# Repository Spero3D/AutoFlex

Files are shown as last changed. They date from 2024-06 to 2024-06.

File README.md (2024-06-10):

# Get Started

## Spero Autoflex is the best solution for the auto-removal process in 3D Printers.

Welcome to the Spero Autoflex documentation! We're excited to introduce you to Spero Autoflex, a revolutionary hardware extension designed to elevate your 3D printing experience.

At Spero, we believe that 3D printing holds immense potential to empower individuals to turn their ideas into reality. Whether you're a hobbyist, a professional maker, or an educator, 3D printing offers endless opportunities for creativity and innovation. However, we recognize that the process of 3D printing can sometimes be challenging, especially when it comes to removing prints from the print bed.

That's where Spero Autoflex comes in. Designed with convenience and efficiency in mind, Spero Autoflex automates the process of print removal, allowing you to seamlessly transition from one print job to the next without the hassle of manual intervention. With Spero Autoflex, you can enjoy a smoother, more streamlined printing process, freeing up your time and energy to focus on bringing your ideas to life.

In this documentation, we'll provide you with everything you need to know about Spero Autoflex – from assembly instructions to usage guidelines and troubleshooting tips. Whether you're a first-time user or a seasoned 3D printing enthusiast, we're here to support you every step of the way.

Thank you for choosing Spero Autoflex. Let's embark on this journey of innovation and creativity together!

# Assembly Guide

## Kickstart your 3D printing journey, build your Spero Autoflex today!

Spero Autoflex is a revolutionary hardware extension designed to automate the process of removing printed parts from your 3D printer's bed. We're thrilled to guide you through the assembly process so you can create your very own Spero Autoflex and elevate your 3D printing experience.

In this assembly guide, we'll walk you through each step of the process, from gathering the necessary materials to assembling the components and calibrating your device for optimal performance. With our detailed instructions and helpful tips, you'll be well on your way to enjoying the convenience and efficiency of Spero Autoflex in no time.

But that's not all – we believe in the power of community and collaboration. That's why we've made all the design files and information readily available on our GitHub repository, allowing you to customize and improve upon the design to suit your specific needs.

Additionally, your support means the world to us. By backing our project, you're helping us bring the final product to market and making Spero Autoflex accessible to creators and makers worldwide. We're immensely grateful for your support and excited to embark on this journey with you.

Let's dive in and start assembling your Spero Autoflex!

Take a look at the diagram below to gain a clear understanding of how to build Autoflex and to receive step-by-step guidance throughout the process.

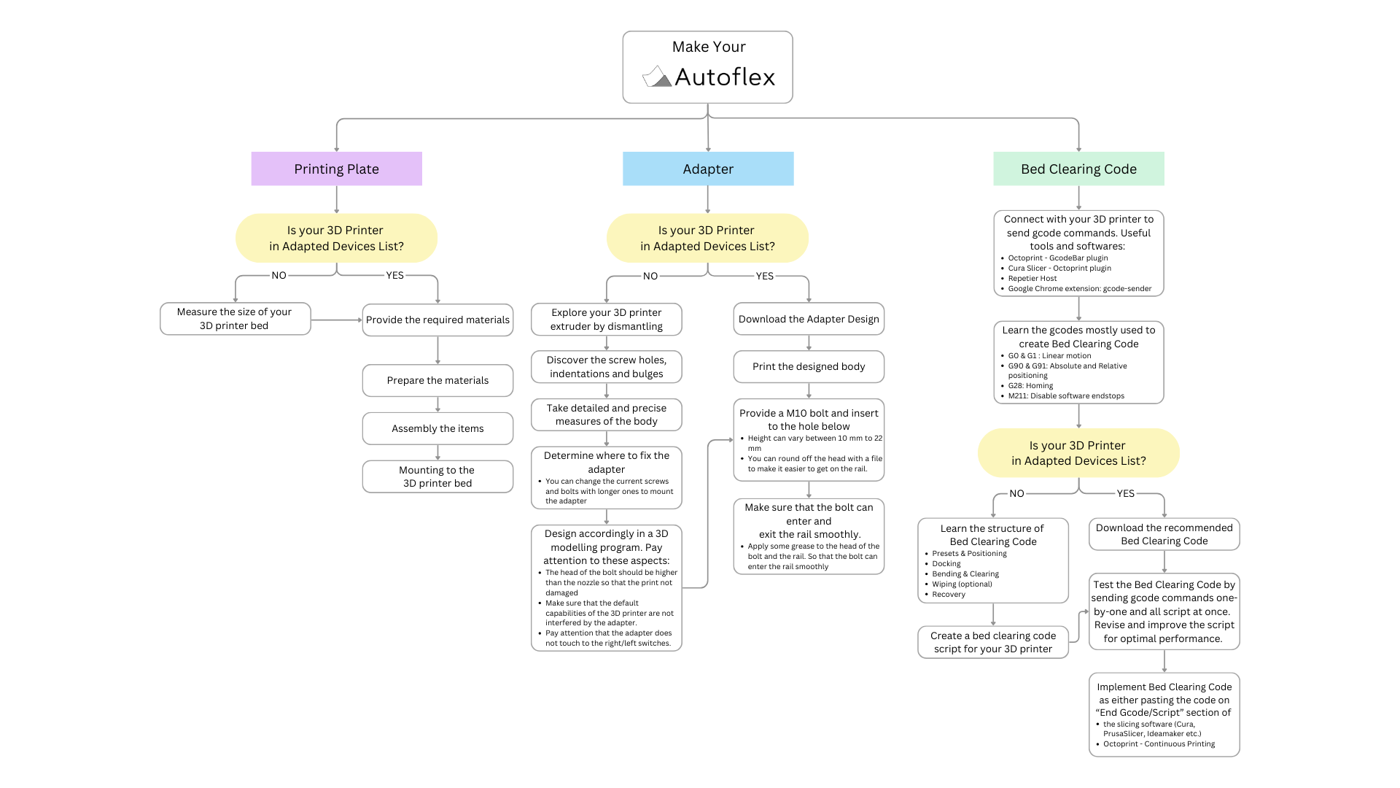
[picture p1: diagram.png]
Autoflex Making Diagram


# Printing Plate

Welcome to the assembly guide for Spero Autoflex Printing Plate!

In this step-by-step guide, we'll walk you through the process of building the printing plate for your Spero Autoflex hardware extension.

Before starting, check the Compatibility and Adaptability to see if your 3D printer is listed among the Adapted Printers.

## Required Materials and Equipment

1. **Spring Steel Sheet Metal**

   - **Thickness:** 0.008" (0.2 mm)
   - **Size:**
     - For Creality Ender-3 Pro: 9.2" \* 10.6" (23.5 cm x 27 cm)
     - For Artillery Sidewinder X1: 12" \* 14.2" (31 cm x 36 cm)
   - For Non-Adapted 3D Printers Recommended Adaptation Steps:
     1. Measure your 3D printer bed sizes.
     2. Add 1.5"(4 cm) to the original y dimension size of your plate to account for extra space at the back.
     3. Get a metal sheet in dimensions x x (y + 4 cm).

2. **Single Track Rail (Ceiling Curtain Track can be used)**

   - **Size:** Same as the x dimension of your 3D printer bed.
     - For Creality Ender 3 Pro: 9.2" (23.5 cm)
     - For Artillery Sidewinder X1: 12" (31 cm)

3. **Kapton Tape**

4. **Two-Sided Mounting Tape**

5. **Any Kind of Fastening Tape** (This could be Blue 3M Tape, Sealing Tape, or Duct Tape.)

6. **Magnetic Sheet**

   - **Size:** Same as the 3D Printer bed measures

7. **Hand/Power Saw** (To cut the rail)

8. **Scissor** (8" Multipurpose scissors would be fine.)

9. **Soap and Water**

10. **Sponge**

11. **Scraper**

## Preparing Materials

### Metal Sheet

Tip: You can cut the 0.2 mm metal sheet with a sharp office scissor.

### Rail

An aluminum or plastic ceiling curtain track can be used. Aluminum rails are recommended due to their strength and resistance to stress. In order to create an open gap that the adapter docks before going in, the rail should be cut 2" (5 cm) inside from the left or right side.

Tip: Oscillating tools with saw blades work great for cutting and are recommended due to safety reasons.

## Assembly the Items

### Step 1: Cover the Steel Sheet with Kapton Tape

For the easiest and cleanest lamination process with Kapton tape, start by dampening the surface with soapy water to create a smooth application. Then, gently press down on the Kapton tape, using a flexible plastic scraper to ensure proper adhesion without leaving any air bubbles or wrinkles.

### Step 2: Fasten the Rail to the Metal Sheet

Use two-sided mounting tape to securely fasten the rail to the back short side of the metal sheet.

### Step 3: Plaster the Magnetic Sheet with Adhesive Back

Prepare the 3D printer bed by plastering and covering it with the magnetic sheet featuring an adhesive back. This step ensures proper adhesion and compatibility with your Spero Autoflex printing plate.

### Step 4: Mount the Spero Autoflex Building Plate to the 3D Printer Bed

Align the metal sheet and the 3D printer bed at the front side, allowing the Spero Autoflex printing plate to extend beyond the bed from the rear. Secure the plate by taping it to the front of the 3D printer bed with duct tape. Then secure the bed and the table by taping them from the inside with blue 3M tape. Make sure the table is firmly attached to the bed and opens and closes smoothly.

Congratulations! Your Spero Autoflex Printing Plate is now ready for use, providing you with seamless and efficient 3D printing capabilities.

# Adapter

The Spero Autoflex Adapter plays a crucial role in the mechanism, acting as a hook that inserts into the rail and effortlessly raises the Spero Autoflex Printing Plate.

## Pathway for the 3D Printers Adapted Before

If your 3D printer is adapted before (you can check from [here](#)), you can follow these steps:

### Step 1 - Download the 3D design of adapter

Download the design of the adapter customized for your 3D printer from [here](#).

### Step 2 - Print the adapter

After slicing the design, print the adapter with a 3D printer. You can use PLA, PLA+, ABS, ASA, PETG filaments for printing.

### Step 3 - Screw in the Bolt

Please provide an M10 bolt with a height between 10 mm and 22 mm, depending on the adapter you use. Screw the bolt into the adapter body, which was previously printed, from the hole below.

**Tip:** You can round off the bolt's head with a file so that it can easily fit into the rail. Do not screw the bolt too deeply; the height of the bolt must be higher than the nozzle to avoid damaging the print.

### Step 4 - Mount to the Extruder

Mount the adapter to the 3D printer extruder using the screws at the predetermined points.

### Step 5 - Test the functionality

Make sure that the bolt can enter to the rail and exit smoothly.

**Tip:** Apply some grease to the head of the bolt and the rail to ensure the bolt enters the rail smoothly.

## Pathway for the 3D Printers Not Adapted Yet

### Step 1 - Explore the Extruder

Explore your 3D Printer's extruder by dismantling. Pay attention to the anchors.

### Step 2 - Discover the Potential Anchors

Identify the potential anchor points, such as screw holes, indentations, and bulges, for installing the adapter to be designed.

### Step 3 - Measure

Take detailed and precise measurements of the extruder and the potential mounting structure.

### Step 4 - Determine Anchors

You can utilize the screw holes, indentations, and bulges.

**Tip:** Alter current screws with longer ones to install the adapter.

### Step 5 - Design the New Adapter

Model the newly customized adapter for your 3D Printer in a 3D modeling program (Autodesk Fusion 360, Onshape, Blender, TinkerCad, etc.)

**Important Considerations:**

- The head of the bolt should be higher than the nozzle so that the print is not damaged.
- Make sure that the default capabilities of the 3D printer are not interfered by the adapter.
- Pay attention that the adapter does not touch the right/left switches.

Afterward, return to the previously adapted 3D printer pathway, located at the top of the page, and install the adapter.

## Contributing to Innovation

Join us in the journey of innovation! Share your adaptation with us on GitHub. Be a part of this transformative process, where many can benefit and contribute to improving designs for the future.

# Bed Clearing Code

The bed clearing code is the final script that initiates the movement to remove the printed part from the bed. Let's dive in!

The Spero Bed Clearing Code comprises specialized G-code commands designed to facilitate the seamless removal of printed parts from the Spero Autoflex Printing Plate, safely guiding them to the front for easy retrieval. This code is executed after the completion of printing, ensuring efficient part removal.

## Connecting with 3D Printer

You can either download the bed clearing code if your 3D printer is among the previously adapted models or create it yourself. In either case, it's important to test the script before using it. Small differences in the mechanics and software of your 3D printer may require fine-tuning the bed clearing code. To do this, you first need to establish a connection that allows you to send G-code commands directly to your 3D printer.

There are several ways to connect with your 3D printer:

### Octoprint & Cura Slicer

If you installed Octoprint to your 3D Printer, you can connect via Cura slicer and send G-code. There is a detailed explanation in the video below:

### Octoprint & Gcodebar Plugin

Octoprint is a free and open-source software providing a useful interface to manage 3D Printers. Install Octoprint on your 3D Printer ([Download Octoprint](https://octoprint.org/download/)).

Gcode Bar Plugin is a free and open-source plugin that enables sending G-code to your 3D Printer. Download and install it from here: [Gcode Bar Plugin](https://plugins.octoprint.org/plugins/gcodebar/).

### Repetier Host

[Repetier Host](https://www.repetier.com/)

### Universal Gcode Sender

[Universal Gcode Sender](https://universalgcodesender.com/)

## Learn Commonly Used G-codes

- **G90** - Absolute positioning - Set all positions and movement in the logical coordinate space
- **G91** - Relative positioning - Interprets all positions relative to the last position
- **G1** / **G0** - Linear movement. For example:
  - `G1 Z200` —> Extruder moves to 200 mm in Z-axis of the coordinate system
  - `G0 X10 Y30` —> Extruder and printing plate move to 10 mm in X-axis and 30 mm in Y-axis of the coordinate system
- **G28** - Home the axis. For example:
  - `G28 X Y` —> Homing only X and Y axes
  - `G28` —> Homing all axes
- **M211** - Disable software endstops

Before continuing, check if your 3D Printer is previously adapted [here](#).

## Pathway for Adapted 3D Printers

### Step 1 - Download the Bed Clearing Code

For now, we can offer a pre-configured code for Creality Ender 3 Pro and Artillery Sidewinder X1. Check from the GitHub repository of Autoflex.

Before using, it is highly recommended to test and fine-tune by using a direct connection with the 3D printer explained above.

**Creality Ender-3 Pro:**

```gcode
M211 S0 ;Disable software endstops
G91 ;Positioning relatively
G1 Z20 ;Move Z-axis 20mm higher
G28 X Y ;Home X and Y axes
G90 ;Positioning absolutely

G1 X230 Y230 ;Go to the upper-right corner 230 mm
G1 Z10 ;Docking the adapter by moving Z-axis 20mm lower
G1 X150 ;Adapter goes into the rail

G1 Z30 ;Lift up the plate
G1 Z60 Y215
G1 Z100 Y185
G1 Z120 Y170
G1 Z140 Y120
G1 Z160 Y170
G1 Z120 Y60
G1 Z200 Y100
G1 Z220 Y50

G1 Z60 Y215 ;Recovery
G1 Z30 Y230
G1 Z7
G1 X230 ;Adapter exits from the rail
G1 Z50 ;Move up the Z-axis

G1 Y205 ;Position for wiping
G1 X160 Z2
G1 Y5 ;Wipe right section
G1 Z50 Y205 X110
G1 Z2
G1 Y5 ;Wipe middle section
G1 Z50 Y205 X70
G1 Z2
G1 Y5 ;Wipe left section

G28 ;Home all axes
M211 S1 ;Enable software endstops
```

## Step 2 - Apply Bed Clearing Code

You can start to use Spero Autoflex by applying bed clearing in several ways.

### Slicer

Paste the Bed Clearing Code into the "End Gcode/Script" section of your slicer software (Cura, PrusaSlicer, IdeaMaker, etc.). This way, the Bed Clearing Code will run and clear the bed after the model is printed.

### Octoprint with Continuous Printing Plugin or OctoPrint-Queue Plugin

Octoprint is a free and open-source software providing a useful interface to manage 3D Printers. Install Octoprint on your 3D Printer ([Download Octoprint](https://octoprint.org/download/)).

Install Continuous Printing and OctoPrint-Queue Plugins, which are free and open-source Octoprint plugins designed for continuous printing.

- [Continuous Printing Plugin](https://plugins.octoprint.org/plugins/continuousprint/)
- [OctoPrint-Queue Plugin](https://plugins.octoprint.org/plugins/queue/)

## Pathway for Non-Adapted 3D Printers

If your 3D printer is not adapted yet, you can easily create a Bed Clearing Code customized for your 3D Printer. You can also contribute to this innovation by sharing this new adaptation with us and others! Upload your adaptation to the GitHub repository of Autoflex!

Before we dive in, let's see how to create a Bed Clearing Code.

Spero Bed Clearing Code may require adjustment based on factors such as the size of the 3D printer bed, the quality of the material used in the plate, or the geometry of the printed parts. Our goal is to explain the structure and logic behind the Spero Bed Clearing Code, empowering you to adapt it to your specific 3D printer and requirements.

### Structure of Bed Clearing Code

1. **Presets and Positioning**

   Before initiating extruder and Spero Autoflex movements, it's essential to ensure that the extruder is positioned correctly and that the 3D printer interprets commands as positions in the logical coordinate space, rather than relative to the previous location. Additionally, you can configure parameters such as extruder movement speed and warning sounds. The Presets and Positioning section of recommended Bed Clearing Code for Creality Ender-3 Pro is like this:

   ```gcode
   M211 S0 ;Disable software endstops
   G91 ;Positioning relatively
   G1 Z20 ;Move Z-axis 20mm higher
   G28 X Y ;Home X and Y axes
   G90 ;Positioning absolutely
   ```

2. **Docking**

   Once the preset and positioning phase is complete, the extruder needs to be moved above the rail to facilitate connection with the Spero Autoflex Adapter. It's crucial to ensure that the bolt can easily enter the rail through the open gap, allowing for a seamless docking process. Pay close attention to alignment and positioning to ensure a smooth connection between the extruder and the rail. The Docking section of recommended Bed Clearing Code for Creality Ender-3 Pro is like this:

   ```gcode
   G1 X230 Y230 ;Go to the upper-right corner 230 mm
   G1 Z10 ;Docking the adapter by moving Z-axis 20mm lower
   G1 X150 ;Adapter goes into the rail
   ```

3. **Clearing**

   During this stage, the Spero Autoflex Printing Plate ascends and executes various movements to ensure the secure removal of printed parts from the surface.

   3.1. **Lifting Up**

   Spero Autoflex Printing Plate elevates, preparing to disengage the printed parts from the surface. The Lifting Up section of recommended Bed Clearing Code for Creality Ender-3 Pro is like this:

   ```gcode
   G1 Z30 ;Lift up the plate
   ```

   3.2. **Bending In and/or Out**

   Spero Autoflex Printing Plate may perform bending movements as necessary to facilitate the detachment of printed parts. The Bending In and/or Out section of recommended Bed Clearing Code for Creality Ender-3 Pro is like this:

   ```gcode
   G1 Z60 Y215
   G1 Z100 Y185
   G1 Z120 Y170
   G1 Z140 Y120
   G1 Z160 Y170
   G1 Z120 Y60
   ```

   3.3. **Leveling**

   Printed parts are gently slid and removed from the plate, ensuring a smooth and controlled extraction process. The Leveling section of recommended Bed Clearing Code for Creality Ender-3 Pro is like this:

   ```gcode
   G1 Z200 Y100
   G1 Z220 Y50
   ```

4. **Recovery**

   In the recovery phase, both the Spero Autoflex Printing Plate and the extruder return to their initial positions. This prepares the 3D printer for the next printing task, ensuring it is ready to proceed without delay. The Recovery section of recommended Bed Clearing Code for Creality Ender-3 Pro is like this:

   ```gcode
   G1 Z60 Y215 ;Recovery
   G1 Z30 Y230
   G1 Z7
   G1 X230 ;Adapter exits from the rail
   G1 Z50 ;Move up the Z-axis

   G28 ;Home all axes
   M211 S1 ;Enable software endstops
   ```

5. **Wiping (Optional)**

   If desired, you can add a wiping section to ensure that the parts are removed from the bed by pushing them with the extruder head. The Wiping section of recommended Bed Clearing Code for Creality Ender-3 Pro is like this:

   ```gcode
   G1 Y205 ;Position for wiping
   G1 X160 Z2
   G1 Y5 ;Wipe right section
   G1 Z50 Y205 X110
   G1 Z2
   G1 Y5 ;Wipe middle section
   G1 Z50 Y205 X70
   G1 Z2
   G1 Y5 ;Wipe left section
   ```

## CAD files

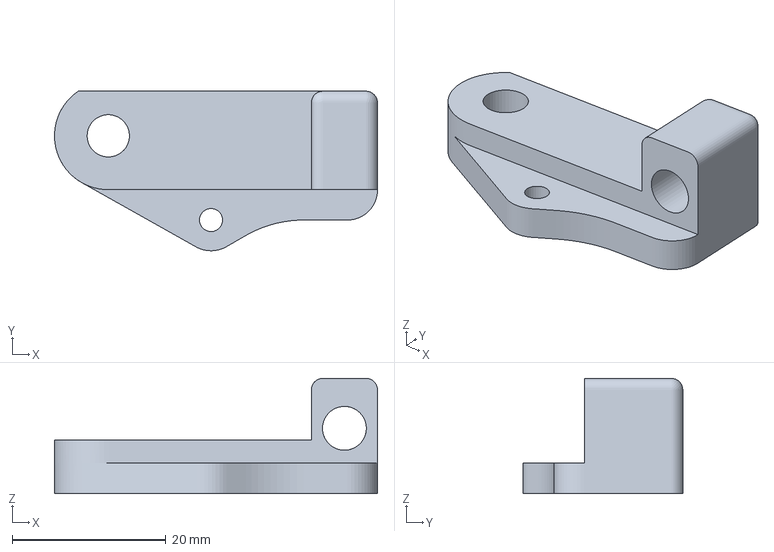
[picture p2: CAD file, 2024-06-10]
Artilliery Sidewinder X1/Adapter/artilliery_swx1_adapter.3mf
42.0 x 20.8 x 15.0 mm

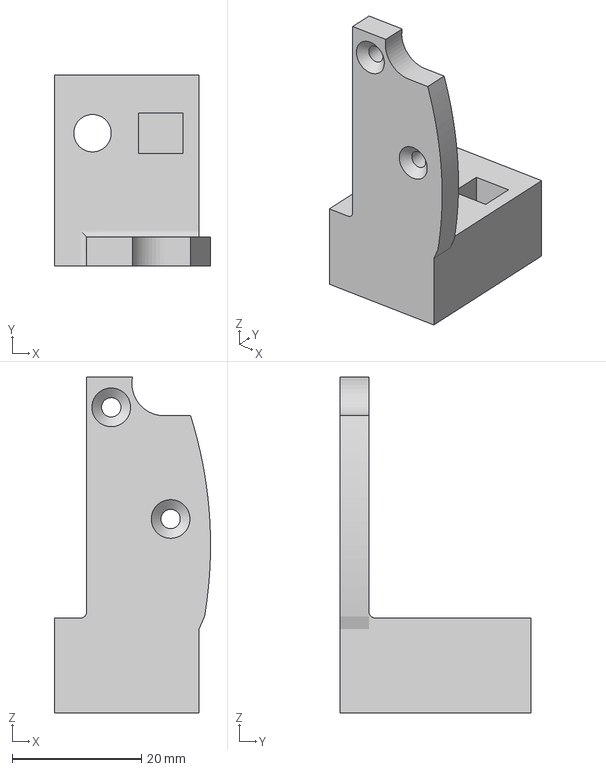
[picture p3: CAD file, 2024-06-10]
Creality Ender-3 Pro/Adapter/creality_ender3pro_adapter.3mf
24.2 x 29.6 x 52.1 mm

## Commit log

2024-06-10 Artilliery Sidewinder X1 file added
    [artilliery_swx1_adapter.3mf]
2024-06-10 Creality Ender 3 Pro file added
    [creality_ender3pro_adapter.3mf]
